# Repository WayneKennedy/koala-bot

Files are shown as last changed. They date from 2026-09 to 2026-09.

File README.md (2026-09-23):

# koala-bot 🐨🤖

An open-source, 3D-printable family of small companion robots — nature-inspired,
affordable, and fully documented (build video + full BOM + software).

**Status:** pre-alpha — *design phase*. Mechanics, electronics, and software are
still converging; nothing is built yet. This repo currently holds the **design
record**. See [`docs/roadmap.md`](docs/roadmap.md) for direction and
[`docs/open-questions.md`](docs/open-questions.md) for what's undecided.

## What it is

**Build order (DEC-62):** first train quadruped walking with four TPU feet.
[Footed rear shanks](docs/design/walking/README.md) interchange at the existing
knees with the wheeled shanks; wheels remain the V1 end goal.

The first family member, **Koala (V1)**, is a **self-balancing, wheel-footed
companion** roughly the size and shape of a koala, printable in **PETG on a
200×200 mm bed**. It sits between *locomotion showpiece* and *desk companion*:
- rolls and balances on two wheel-feet (rear legs, wheels at the ankles);
- crouches and stands on articulating knees, leans into turns via 2-DOF hips;
- gestures with 3-DOF dual-purpose front limbs (arms *and* forelegs);
- looks at you with a 3-RPS parallel neck (yaw delegated to the mobile base).

Locomotion is ground-based; a **climbing sibling** is a planned later family
member. Full intent, morphology, and principles: [`docs/concept.md`](docs/concept.md).

## Repo map

| Path | Contents |
|---|---|
| [`docs/`](docs/) | The design record — concept, architecture, decisions, roadmap, BOM, sourcing (**start here**) |
| [`hardware/`](hardware/) | CAD / printable parts (parametric code-CAD — draft v0 lower body) |
| `firmware/` | Real-time MCU code — balance loop, servo bus (planned) |
| `software/` | Pi / ROS2 high-level brain + tooling (planned) |
| [`LICENSING.md`](LICENSING.md) | Tri-licence (hardware / software / docs) |

## Docs are written AI-first

Most docs assume an **AI assistant is the primary reader** — dense, factual,
cross-referenced, greppable — and every artefact meets the **4Cs**
(Correct · Complete · Coherent · Concise). See [`AGENTS.md`](AGENTS.md).

## License

Tri-licensed — `CERN-OHL-S-2.0` (hardware) · `MIT` (software) · `CC-BY-SA-4.0`
(docs). See [`LICENSING.md`](LICENSING.md). Full licence texts are in `LICENSES/`.

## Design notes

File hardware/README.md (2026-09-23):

# hardware/

Parametric build123d CAD, CERN-OHL-S-2.0. Current 2026-09-19 CAD implements
recessed **roll → pitch → elbow** front limbs and **pitch → roll → knee** rear
limbs, with rear ankle drives and replaceable TPU front pads. Design, assembly,
dimensions and remaining acceptance gates:
[cad-integrated-design.md](../docs/cad-integrated-design.md).

**2026-09-21:** the first build uses four TPU feet (DEC-62). `foot_shank` v1
replaces each complete wheeled rear shank at the existing knee; the same
`front_contact_pad` v1 fits all four feet. The default viewer configuration is
`walking`; `quadruped` and `upright` retain the wheeled geometry.
[Print files, assembly and evidence](../docs/design/walking/README.md).

## Current CAD

The torso now wraps the front A volume, with a **10 mm socket-lip recess**,
removable front-access shoulder cassettes and a cap at body Z183.5; the
hip-to-shoulder axis separation remains **150 mm**. The front carrier, upper arm
and forearm apply the rear redesign's broad print planes, open forks and
accessible supports. Front B/C shafts are parallel. The main assembly carries
DEC-61's **45° rear pitch socket mount**, with rear driver corridors through the
actual torso. [Front revision and evidence](../docs/design/front-redesign/README.md).

`params.py` supplies body/interface dimensions. `servo_iface.py` implements the
measured four-ear SO-101 saddle and horn references. `parts/links.py` carries the
rear links/carriers; `parts/front.py` implements the front chain,
`parts/shoulder_mount.py` its independent cassettes, and `parts/pelvis.py` the
unchanged proven root socket. `parts/torso.py` and `parts/e_tray.py` complete the
chassis. `parts/neck_space.py` reserves small STS3032M neck-servo space and a
cartridge interface; it does not build an accepted 3-RPS mechanism or neck print.
`body_plan.py` and `assembly.py` share the declared pose geometry; front and rear
use different serial joint transforms.

Source paths above are relative to `src/koala_hardware/`. All commands below
run from `hardware/`:

```sh
uv run python -m koala_hardware.export
uv run python -m koala_hardware.assembly
uv run python -m koala_hardware.audit
uv run python -m koala_hardware.audit --fallback --nominal-only
uv run python -m unittest discover -s tests
uv run python -m koala_hardware.body_plan --output ../docs/design --cad
uv run python -m koala_hardware.viewer --build
uv run python -m koala_hardware.mjcf          # MuJoCo model -> sim/koala_walking.xml + meshes/ (--crude: capsule visuals); docs/architecture.md
```

Exports: `build/stl/`, `build/step/`, `build/renders/`, `build/manifest.txt`.
`sim/` holds the generated MuJoCo model: one visual STL per rigid body in `sim/meshes/` (2.7 MB,
committed; regenerate after any CAD change), explicit per-body inertia from the BREP, and the
assumptions in the XML header. `mjcf_check.py` loads it from any venv that has MuJoCo (not a
dependency here) and reports masses, CoM against the feet, a 3 s stand and a render.
Full assemblies are `build/step/koala-walking.step`, `koala-quadruped.step` and `koala-upright.step`.
Every handed print has explicit left/right files. Removed part outputs are
pruned. The exporter regenerates the printed and fastening blocks in
[the BOM](../docs/bom.md); never hand-edit them. Slice results count only when
their SHA-256 matches the current STL.

Every structural print must be one valid solid, export a watertight positive-volume
STL and fit the 200 mm bed in its
stated orientation. Local supports/brims are explicit under DEC-39; flagged
surface areas remain visible in the manifest/BOM and need layer inspection.
They are not a reason to reintroduce unnecessary structural seams.

`audit.py` checks the measured interface, selected screw/tool paths, motor
insertion, real frame contacts and sampled full assemblies including nominal
fastener heads. `--fallback` uses the conservative stepped case instead of the optional
local STEP. Reports are `build/audit.json` and `build/audit-fallback.json`.
Samples are not continuous motion, loaded operating limits or physical fit.
Head placement and mounting are undecided; the placeholder is omitted from
structural CAD/viewer. Neck, complete battery/electronics packaging and
harness/guards remain open. `leg_sizing.py` retains the explicitly historical
DEC-32 analytical study; it does not size the current robot.

## Viewer and independent images

**DEC-46/48:** sliders use pose-dependent mechanical-clearance ranges for the
printed parts and nominal hardware. The static build warms geometry/engine-hashed
caches using Node.js. A browser worker recomputes bounds after each change.
The search uses 0.25° samples and a 2° reserve before the first obstruction;
these are not calibrated servo or loaded operating limits. Ground contact and
complete harnesses are outside the search. Current main-viewer browser and
solid-CAD endpoint checks are in the
[front revision evidence](../docs/design/front-redesign/README.md#digital-evidence-and-limits).
The earlier `docs/design/manufacturing/travel-endpoints.json` predates the
current links; each report validates only its recorded revision.

Build the separate rear-leg review with `uv run python -m koala_hardware.rear_leg_review`
(add `--thigh-options` for the 2026-09-19 thigh print-form comparison, left leg
option 1, right leg option 2: [record](../docs/design/rear-leg/thigh-options/README.md);
`--thigh-flat` for the owner's chosen one-piece tapered thigh on both legs:
[record](../docs/design/rear-leg/thigh-flat/README.md));
the existing server then exposes it at
[rear-leg/](https://blake.tail13a0c0.ts.net:8443/rear-leg/).

[Blake viewer](https://blake.tail13a0c0.ts.net:8443/) is the canonical instance
(DEC-35), served by [systemd/koala-viewer.service](systemd/koala-viewer.service).
It serves a static build. After source changes, run `viewer --build` on blake
and reload; a service restart also rebuilds. The body selector switches between
walking, wheeled quadruped and wheeled upright snapshots. Sliders apply joint adjustments, **not a
validated rise trajectory or safe operating limits**.

For a local viewer:

```sh
uv run python -m koala_hardware.viewer --serve --no-open --port 8020
```

For browser/CAD parity, with Playwright Chromium installed or
`PLAYWRIGHT_CHROMIUM` set:

```sh
uv run --with playwright python tests/viewer_smoke.py
```

Independent PNG/SVG drawings and structural views are in
[docs/design/](../docs/design/README.md), including copies on blake for iPad
Files. Refresh the kinematic PNGs with:

```sh
uv run --with playwright python -m koala_hardware.body_plan --output ../docs/design --cad --png
```

The Parts tab shows per-part `printable` tags, materials, print orientations and assembly notes;
it is not a packed print plate. Bought references are not printable parts.

## Physical acceptance

The maintainer confirms ST3215 fit in SO-101 parts in PLA+/PETG (DEC-33).
There is no repeat-gauge/caliper prerequisite. The two `coupon_socket_*`
designs remain available to investigate a specific new fit issue. Check the
current assembly's insertion/removal, M2/M3 engagement, centre-head/boss
clearance, Back washers, axial preload and real connector access. Log results
by exact print version in [the test log](../docs/test-log.md).

Root socket v1 is physically proven with its recorded ear-hole support caveat;
hip carrier v1 has plate 2 slices but no recorded physical result. Continue with version-specific fitting,
one rear leg, the pair, front limbs and documented load/creep/transition checks.
Actual masses, CoM and power budgets remain open. No digital check closes these gates.

`slice_remote.py` must not run on the printer host while printing is active.
Local slicing does not submit or start a print. Generic motor/hole/insert
coupons remain available; record results, including no change, in the test log
and store calibrated constants in `params.py`.

## Local manufacturing slices

`uv run python -m koala_hardware.manufacturing_slices` uses local PrusaSlicer,
reads the shared printer profile from the sibling 3d-printing checkout and adds
`print/manufacturing-*.ini` project settings (support from the bed only, never off the part:
the house rule, learned on plate 1; `-tree.ini` for organic support, one part per job). It records exact STL hashes and
layer-path images in `docs/design/manufacturing/`. It never submits a print.
Changed torso v5, shoulder mount v1, front carrier v3, upper arm/forearm v2 and
thigh v3 remain `unknown`; local toolpaths alone do not establish physical
printability. Root socket v1 is `proven` with its documented caveat; unchanged
parts retain their recorded tags. See [the part review](../docs/part-design-review.md).
TPU settings are provisional until matched to the actual spool.

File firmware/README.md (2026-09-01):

# firmware/

Real-time MCU code (planned - Phase 1). The "spinal cord".

- Runs the **balance loop** (IMU -> PID -> wheels, ~200-1000 Hz, deterministic), the
  servo-bus driver, encoders, safety.
- **micro-ROS** node exposing the topic contract (see [`../docs/architecture.md`](../docs/architecture.md)).
- MCU: Teensy 4.0 (DEC-18). Licence: `MIT`.

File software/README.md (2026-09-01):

# software/

Pi 5 / ROS2 high-level brain + tooling (planned - Phase 1). The "cerebrum".

- Perception (camera-eyes), behaviour/mission, LLM personality, networking.
- Sends setpoints to the MCU, reads telemetry - never runs the balance loop.
- Licence: `MIT`.

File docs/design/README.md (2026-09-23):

# Engineering drawings and CAD

**2026-09-21 addition:** [walking first build](walking/README.md), with four
identical TPU feet and interchangeable `foot_shank` v1 rear links. The main
viewer opens in this configuration; the wheeled snapshots remain selectable.

**Current 2026-09-19 revision:** [recessed roll-first front limbs](front-redesign/README.md),
[small-servo neck provision](neck-provision.md),
[design and assembly](../cad-integrated-design.md), and
[part-by-part printability](../part-design-review.md). The torso wraps the front
A modules while retaining 150 mm hip-to-shoulder spacing. New front parts and
changed torso/thigh remain unprinted; older slices validate only matching hashes.

The [rear-leg record](rear-leg/README.md) documents DEC-57/58's origins and later
print-form studies. DEC-61's inclined rear mount is now implemented in the main
assembly. Current thigh v3 corrects rounding; shank v2 is unchanged. Earlier
[carrier-orientation alternatives](carrier-orientation/README.md) and
[front-carrier flat-back study](front-carrier/README.md) are historical, not
competing current mounts.

[SO-101 source templates and interface comparison](so101/README.md) retain the
measured construction reference. [Manufacturing records](manufacturing/README.md)
distinguish local slices from physical proof; root socket v1 is proven with its
recorded ear-hole caveat.

**Historical knee packaging study, deferred by DEC-43:**
[PNG](knee-packaging.png) · [SVG](knee-packaging.svg) ·
[Results](knee-packaging.json) · [Interpretation](../knee-drive-packaging.md).
This records the rejected knee-wheel detour and is not the current structure.

These PNGs open directly in the iPad Files app. Copies are kept in this same
repo path on blake.

| View | Quadruped | Upright |
|---|---|---|
| Dimensioned body master | [PNG](body-quadruped.png) | [PNG](body-upright.png) |
| Scalable body master | [SVG](body-quadruped.svg) | [SVG](body-upright.svg) |
| Actual structural CAD, side | [PNG](cad-quadruped-side.png) | [PNG](cad-upright-side.png) |
| Actual structural CAD, perspective | [PNG](cad-quadruped.png) | [PNG](cad-upright.png) |
| Kinematic STEP reference | [STEP](body-quadruped.step) | [STEP](body-upright.step) |

The master drawings and detailed CAD share their joint centres: 70 mm upper
arms, 75 mm forearms plus 25 mm hand extensions to Ø32 mm ball centres,
85/90 mm rear links, 150 mm torso, 450 mm upright height and 220 mm rear track.
Unrolled front ball centres are now 190.23 mm apart and 260 mm ahead of the
rear wheels in supported stance. Only the rear Ø80 wheels are driven. Front
shoulders are roll → pitch; rear hips remain pitch → roll. The body-master head outline is a sizing allocation only; it is omitted from
the structural CAD and viewer because position and mounting are undecided.

[Joint coordinates](body-plan.json) · [Design and assembly](../cad-integrated-design.md) ·
[Digital validation](cad-validation.json) · [Body-layout rationale](../body-layout.md).

## Individual structural prints

Exporter PNGs show the print orientation; files ending `-views.png` show native
CAD coordinates for shape review. Current [layer plots](front-redesign/README.md#local-slicing-and-support-review)
show the chosen bed faces. Left/right STL and STEP files are generated separately.

| Print | Image |
|---|---|
| Proven root socket v1 (four physical prints) | [PNG](parts/root_socket_right.png) |
| Recessed shoulder cassette v1 | [Four views](parts/shoulder_mount-views.png) |
| Roll-first shoulder carrier v3 | [Four views](parts/shoulder_carrier-views.png) |
| Rear hip carrier v1 | [PNG](parts/hip_carrier_right.png) |
| Drive/idler socket slots | [PNG](so101/socket-slot-comparison.png) |
| Corrected thigh v3, 85 mm | [Four views](parts/thigh-views.png) |
| Upper arm v2, 70 mm | [Four views](parts/upper_arm-views.png) |
| Shank v2, 90 mm | [PNG](parts/shank_right.png) |
| Footed rear shank v1, 90 mm | [Four views](parts/foot_shank-views.png) |
| Forearm v2 and keyed hand end | [Four views](parts/forearm-views.png) |
| Replaceable Ø32 TPU contact | [PNG](parts/front_contact_pad.png) |
| Extended torso v5 | [Four views](parts/torso_frame-views.png) |
| Electronics tray | [PNG](parts/e_tray.png) |
| Two-print acceptance rig | [Saddle](parts/coupon_socket_saddle.png) · [Fork](parts/coupon_socket_fork.png) |

Full structural STEP assemblies are generated in
`hardware/build/step/koala-walking.step`, `koala-quadruped.step` and `koala-upright.step`; the current
part STL/STEP sets are in `hardware/build/stl/` and `hardware/build/step/`.
These build outputs also exist on blake. Original upstream reference STEPs
remain unchanged in `hardware/vendor/`; they are not koala prints.

## Regenerate

From `hardware/`:

```sh
uv run python -m koala_hardware.export
uv run python -m koala_hardware.manufacturing_slices
uv run python -m koala_hardware.assembly
uv run python -m koala_hardware.audit
uv run python -m koala_hardware.audit --fallback --nominal-only
uv run --with playwright python -m koala_hardware.body_plan --output ../docs/design --cad --png
uv run python -m koala_hardware.viewer --build
```

PNG rendering requires Playwright Chromium, or `PLAYWRIGHT_CHROMIUM` set to an
installed binary. CAD scene PNGs come from the browser regression captures;
individual print PNGs come from the exporter. No image is evidence of slicing,
physical fit, continuous collision clearance, strength or a validated rise.

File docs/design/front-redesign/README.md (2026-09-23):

# Recessed roll-first front limbs — 2026-09-19

**Unprinted revision, not a banked decision.** The owner requested the four CAD
review findings be fixed, then the rear redesign's printability lessons applied
to roll-first front limbs, with the torso extended around recessed A servos and
provision for the three small neck servos. This record describes the resulting
prototype. [Current chassis and assembly](../../cad-integrated-design.md) ·
[Printability by version](../../part-design-review.md).

## Geometry and visual review

| Item | Result | Review image |
|---|---|---|
| Torso v5 | 150 mm hip-to-shoulder spacing retained; cap at body Z183.5; ±47 mm sides, shallow forward chest step, rear screw-driver corridors | [Four views](../parts/torso_frame-views.png) |
| Shoulder mount v1 | Separate left/right cassettes support unchanged proven root sockets; socket lips at ±37 mm give 10 mm recess; four front-access M3×20 per side | [Four views](../parts/shoulder_mount-views.png) |
| Shoulder carrier v3 | Longitudinal A roll, B pitch 40 mm outboard; broad common block/socket bed plane and open driver tunnels | [Four views](../parts/shoulder_carrier-views.png) |
| Upper arm v2 | 70 mm centres, parallel B/C shafts, thickened cup wall sharing the outer fork's print plane | [Four views](../parts/upper_arm-views.png) |
| Forearm v2 | 100 mm elbow-to-pad centre, longer open elbow fork, flat tapered shaft, unchanged keyed TPU pad | [Four views](../parts/forearm-views.png) |
| Thigh v3 correction | Earlier successful fillets now survive later split-group rounding operations; joint datums unchanged | [Four views](../parts/thigh-views.png) |

**Does the design look stupid?** Individual review: **no**. The torso/cassettes
form a compact cage with broad rails, a shallow chest step and inward socket
flanges, without outriggers or disconnected features. The front carrier and
links have continuous printable forms rather than thin unsupported decorative
features. They are acceptable structural prototypes, not an accepted finished
shell. V5's inward dorsal taper was also inspected in multiple views: it
narrows the upper back without adding a backpack or increasing the 94 mm front
width / 82 mm depth envelope. The
[assembled body views](body-views.png) were also reviewed: depth stays compact,
the front shoulder span approaches the rear wheel span, and the different
front/rear limb forms look deliberate. The head remains a sizing allocation,
so this is not approval of a finished koala shell or loaded gestures.

The recess is measured from the torso side envelope to the **socket lip**;
A's output region, horns and moving carrier project outside it. A centres are
110.23 mm apart, pitch centres 190.23 mm apart. Rear pitch centres remain
52.5 mm apart and rear wheel track remains 220 mm. Left/right symmetry is
retained; front and rear use different serial joint orders by design.

The first extended torso (v4) cleared the nominal pose but its dorsal rails
clipped the front carrier at **+1° roll**. V5 tapers those rails from Y±43 to
Y±29 over body Z106…122; the outer width, depth and socket-lip recess stay
unchanged. The cartridge hole pattern shifts +10 mm in X to clear the upper
rails. This is a correction found by moving-package checks, not evidence that
a nominal screenshot alone established travel.

The B35 shoulder-carrier v2 trial also exposed a limitation beyond nominal
checks: the full upper-arm/A-case sweep stopped at about **+6° roll**. Final
carrier v3 puts B **40 mm** outboard. At the examined ±28/29/30° roll samples
in both saved poses, B39 left 0.765 mm upper-fork / 1.065 mm horn-head clearance
to the conservative A case; B40 increases those sampled minima to
**1.765 / 2.065 mm**. Upper arm/forearm v2 and torso v5 stay unchanged.
The larger margin is a geometric allocation, not a proven loaded range.

The [neck provision](../neck-provision.md) reserves small STS3032M space and
four generic cartridge mounts, including fixed-lead routing allowance. These
reference boxes neither establish the bought variant's fit nor solve 3-RPS
linkage geometry. No new neck print is claimed.

## Printability and service

New shoulder mount v1, torso v5, front carrier v3, upper arm/forearm v2 and thigh
v3 remain **`unknown`** despite local slicing; physical support removal, fit and
strength are unverified. Root socket v1 remains **`proven`** with its ear-hole
support caveat. Unchanged shank v2 and hip carrier v1 retain `assumed`.

The carrier prints on its common block/cup floor, the upper arm on its shared
drive-side fork/cup plane, and the forearm on its broad −Y face. Open forks
make supports accessible. Seven short/narrow upper-arm junction edges reject
R2 and remain sharp; the builder warns explicitly instead of silently undoing
rounding. The accepted ear seats, horn webs and driver approaches remain.

Recessing A would obstruct installed inboard root screws. **Load the four frame
nuts into the bare cassette first:** a fitted root blocks the two inner nuts'
straight insertion paths. Then bolt the root to the cassette on the bench and
attach the complete cassette to the ventral frame with four front-access screws.
For root service, remove those frame screws and slide the cassette **laterally
outward**, keeping the opposite A module installed. The seam has a service purpose; links remain single prints.
This 2026-09-19 wheeled revision uses 26 physical prints from 18 designs /
26 handed exports, including six coupon designs. The later
[walking addition](../walking/README.md) adds an interchangeable rear-shank
design and two extra TPU pads for that configuration.

## Local slicing and support review

[Machine-readable slice records](slices.json) identify each STL/G-code version
and hash, plus the base profile and override hashes. PrusaSlicer **2.7.2** came
from the Ubuntu noble package, extracted locally with dependencies; no host
installation or printer connection was used. Review settings were **0.2 mm
layers, four walls, 30% gyroid, 4 mm brim and organic supports from the bed only**.

| Current part | Selected deposited-layer views |
|---|---|
| Forearm v2 | [Left](forearm_left-layers.png) · [Right](forearm_right-layers.png) |
| Shoulder carrier v3 | [Left](shoulder_carrier_left-layers.png) · [Right](shoulder_carrier_right-layers.png) |
| Shoulder mount v1 | [Left](shoulder_mount_left-layers.png) · [Right](shoulder_mount_right-layers.png) |
| Upper arm v2 | [Left](upper_arm_left-layers.png) · [Right](upper_arm_right-layers.png) |
| Thigh v3 | [Left](thigh_left-layers.png) · [Right](thigh_right-layers.png) |
| Torso v5 | [Layer views](torso_frame-layers.png) |

The selected layer plots show broad bases and support trees outside the solids
or in open forks/cups, without an enclosed support cage in the inspected layers.
The torso v5 plot shows branches through its open cage to the opposing rails
and cap. **All 11 final review slices match the current STL versions/hashes**,
including carrier v3 and torso v5, with **zero recorded slicer diagnostics**.
The final carrier layers and B40 body views have been inspected. Selected
layers do not establish every layer start or physical support removal;
surface quality, fit and strength remain unverified and changed parts stay
`unknown`. Tiny forearm STL coordinate roundoff was corrected by persisting the
same default vertex merge already used in mesh validation; BREP geometry and
merge tolerance did not change. [Digital correction](../../test-log.md#2026-09-19--forearm-v2-stl-roundoff-persistence-corrected-digital-only).

Shank v2 is outside this 11-slice batch. [OQ-22](../../open-questions.md)
records earlier organic slices with STL hash prefixes 335d9f74 (left) and
ae2ac311 (right), matching the current exports; those G-code files and layers
were not re-reviewed here. Older manufacturing-report shank slices predate v2.

To reproduce one organic review slice, run from `hardware/` with an
organic-capable PrusaSlicer and the sibling `3d-printing` checkout:

```sh
mkdir -p build/manufacturing
prusa-slicer \
  --load ../../3d-printing/reference/ender5s1_petg_koala.ini \
  --load print/manufacturing-petg-tree.ini \
  --export-gcode \
  --output build/manufacturing/upper_arm_right-v2-tree.gcode \
  build/stl/upper_arm_right.stl
```

Substitute the current exported part name and version for other parts, slicing
one at a time. Match the recorded slicer/profile hashes when comparing this
review's toolpaths. The command writes a local file; it does not submit a print.

## Digital evidence and limits

The [consolidated validation record](../cad-validation.json) links the final
versions, exports, slices and main/rear checks.

The [complete driven-package report](driven-package-clearance.json) is the
primary shoulder roll check: **outward-positive commanded roll −30…30° at 2°
intervals**, in both saved pitch/elbow configurations. It checks the entire
right moving front chain and hardware against its fixed A imported/caliper
cases, socket module, cassette and fixings: **31 samples / 2,604 pairs per
pose, zero overlap**. It covers the upper-arm/A-case interaction missed by the
earlier carrier-only trial.

The [installed-front report](installed-front-clearance.json) also moves **both
front limbs** at roll −30/−25/0/+25/+30°, with the rear limbs nominal, in both
saved poses and with both imported/caliper cases. All pairs involving the
moving fronts participate against the torso, catalogue neck envelopes, fixed
roots, opposite front limb and stationary rear hardware, except the intended
owning-socket contact regions: **20 configurations / 1,236 candidate solid
pairs, zero hits**. These two reports identify their geometry-source hashes.

Additional evidence has narrower scope:

| Check | Scope and result |
|---|---|
| [Adjacent joints](local-clearance.json) | 1° samples with both case models: native carrier-only roll −30…60°, pitch ±90°, elbow 0…120°; 2,296 pairs, zero overlap. The native roll axis/range is not the whole-limb commanded range above. |
| [B-offset study](roll-offset-study.json) | Documents the B35 obstruction and B40 choice; sampled conservative A-case margins at ±28/29/30° are 1.765 mm for the upper fork and 2.065 mm for horn heads. |
| [Dorsal-rail sweep](shoulder-rail-sweep.json) | Final B40/carrier v3 and torso v5: 12 moving front-chain solids against conservative unfilleted rail/transition envelopes over ±30° roll at 2° in both saved poses, zero overlap. |
| [Complete assembly audit](assembly-audit.json) | 62 samples around both saved poses pass; each nominal pose checks 180 pairs. Also checks the 19-angle interface rig, insertion, frame contact and driver paths. |
| [Fallback audit](assembly-audit-fallback.json) | Both nominal poses pass with conservative parametric servo cases; 180 pairs each. |
| Neck and service access | Reserved neck volumes/four cartridge driver paths clear; three service regressions protect cassette nut loading/seating and lateral removal. |
| Python regression suite | **65 tests pass**, including version guarding, front print/kinematic checks and STL closure after merging only identical coordinates. |
| Exports and slicing | **26 handed part exports, two assembly STEP exports, 11 current review slices** pass; generated BOM updated. |
| [Main browser verification](browser-verification.json) | Both poses, all three sliders, mirrored CAD/browser motion, backdrop alignment, part metadata and reset pass; four current captures inspected. |
| [Main viewer endpoints](viewer-endpoints.json) | All 12 initial grouped-slider endpoints checked against the complete assembly with both case models: 24 configurations / 1,452 candidate solid pairs, zero hits. |
| [Rear production review](../rear-leg/README.md) | Refreshed current parts, sections and views; both browser poses/seven checks and all 12 initial bounds plus four combined solid-CAD configurations pass. Front/neck geometry is omitted from this separate review. |

The main viewer rolls all four limbs together. Its initial common roll range
is **−5.5…29.25°** in quadruped and **−5…29.25°** upright, including the 2°
search reserve. Rear motor proximity sets the inward bound; the front socket/
carrier sets the outward bound. The front-only ±30° checks above leave the
rear joints nominal and therefore do not establish that grouped range.

The solid intersection threshold is **0.01 mm³**. These are finite samples,
with stated pose/obstacle coverage, not continuous swept volumes, calibrated
servo limits or loaded motion. Ground interaction, full cables, guards and
as-built tolerances are not established. The earlier four findings and their
corrections are recorded in the [test log](../../test-log.md#2026-09-19--four-cad-review-defects-corrected-digital-only).

The **main browser smoke and solid-CAD endpoint checks pass**; its four current
pose/view captures have been inspected. A [metadata-only refresh](viewer-metadata-refresh.json)
updates prior hip/shank slice notes and verifies every non-note scene field is
unchanged. The rear review also passes its browser and endpoint checks. Of its
16 broader exploratory rear-assembly samples, 15 clear; quadruped pitch −45°
intersects torso/thigh outside the current −28.25° viewer bound. That sample is
not accepted travel. Earlier manufacturing reports and
thigh v2 slices do not validate these revised parts. No physical print,
fitting, support removal, load/creep or loaded transition is asserted by this record.

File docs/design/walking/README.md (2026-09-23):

# Walking first build — interchangeable rear shanks

**2026-09-21, DEC-62.** `foot_shank` v1 replaces each complete wheeled `shank`
at the existing knee. It has no motor mount or drive hardware and uses the
**unchanged `front_contact_pad` v1**: four identical Ø32 TPU feet on the first
robot. Wheeled shank v2 remains the V1 end goal.

[Four-view shape review](../parts/foot_shank-views.png) ·
[Assembly](assembly.png) · [Side](assembly-side.png) ·
[Walking schematic](../body-walking.png) · [SVG](../body-walking.svg) ·
[Main viewer](https://blake.tail13a0c0.ts.net:8443/) (opens in “Walking · four TPU feet”).

## Parts and exchange

| Print | Qty for walking | Files |
|---|---:|---|
| `foot_shank_left` v1, PETG | 1 | [STL](../../../hardware/build/stl/foot_shank_left.stl) · [STEP](foot_shank_left-v1.step) |
| `foot_shank_right` v1, PETG | 1 | [STL](../../../hardware/build/stl/foot_shank_right.stl) · [STEP](foot_shank_right-v1.step) |
| `front_contact_pad` v1, TPU | 4 total | [STL](../../../hardware/build/stl/front_contact_pad.stl) |

STLs are generated local build outputs; run the exporter after cloning.
The full structural assembly is
[`koala-walking.step`](../../../hardware/build/step/koala-walking.step).
The generated [BOM](../../bom.md) counts **28 physical prints walking** and
**26 wheeled**, excluding coupons and unfitted alternatives from each total.

Each rear foot is 90 mm from knee axis to ball centre; front reach stays
100 mm. Native X is the knee shaft, +Z points toward the pad. The rear knee's
36.4 mm horn span, square holes, head recesses and driver paths are retained.
No new ankle joint or structural seam is introduced. The front v2 geometry
and all existing part versions are unchanged; the ledger adds `foot_shank` v1.

Insert the captive M3 nut from the shank's side before fitting the keyed pad.
Use the same recessed M3×20 screw and plain washer as the front foot. Mount
the fork on the knee's drive/idler horns using the existing eight square
screws, drive-centre retention and four idler washers. For conversion,
support the robot, isolate power and exchange the whole handed lower links
at those horn interfaces; the knee servos stay in the thighs. Fit the
retained motor/hub/wheel packages to wheeled shank v2 and use the matching
kinematics, calibration and mass model.

## Stance and clearance scope

The walking CAD reference retains the supported torso and front limb pose.
Rear contact X remains −55 mm; pad centres are Z16 instead of the wheel
axles' Z40. Rear knees are re-solved for the retained 85/90 mm links. All four
TPU surfaces touch Z0. Neutral rear foot spacing is **132.6 mm**; front foot
spacing is 190.23 mm. **220 mm is the wheeled track**, not walking-foot spacing.
The `walking` reference is a standing configuration, not a trained gait.

- Four-view shape gate passed before export: short front-style taper, open
  fork and broad flat print face; no leftover motor bracket.
- Both handed exports are connected, valid solids with closed positive-volume
  meshes; each fits within **49.0 × 103.4 × 20.8 mm** in its print orientation.
- Regression checks cover common horn interfaces/driver paths, identical
  keyed terminal geometry, nut access, pad/head clearance and per-build BOM
  counts. The full Python suite passed 71 tests; the JavaScript transform
  regression also passed.
- The complete shank **and pad** clear the adjacent thigh and knee case at
  **0–120° bend in 10° increments**, with imported and conservative cases.
  This local check is separate from whole-robot slider travel.
- [Assembly samples](assembly-samples.json): 27 shared-control combinations
  at −5/0/+5° roll/pitch/bend plus four opposed-left pitch/bend samples pass.
  [Nominal audit](assembly-audit.json) and
  [conservative-case audit](assembly-audit-fallback.json) include all three
  configurations and the existing mounting/access checks.
- [Viewer endpoints](viewer-endpoints.json): all six initial walking slider
  endpoints pass independent solid-CAD checks with both case models. Browser
  checks cover walking and both retained wheeled poses, left/right motion,
  pad/shank tags, backdrop alignment and resetting the controls.
  [Validation record](validation.json) lists the commands and results;
  [source/export manifest](manifest.json) records the reviewed version and hashes.

These are discrete, nominal CAD checks. They do not prove continuous travel,
floor clearance during slider motion, cable routing, loaded gait, strength or
safe servo limits. Ground reactions, training setup and physical foot/load
acceptance remain OQ-16/17/19.

## Print approach and local slices

`foot_shank` v1 is **unknown / unprinted**. Print with its broad native −Y face
on the bed. The existing fork bores/head reliefs and nut-slot roof need
accessible local supports. The new rear part inherits the front construction,
not physical proof of fit or strength.

[Slice records and hashes](slices.json) ·
[Left layers](foot_shank_left-layers.png) ·
[Right layers](foot_shank_right-layers.png).

Both handed v1 exports were sliced with the recorded shared PETG profile and
Koala's `manufacturing-petg-tree.ini`: organic support from the bed only,
0.2 mm layers, four perimeters, 30% infill, 4 mm brim. Each has 104 layers,
zero reported slicer diagnostics and approximately **3 hours / 30 g PETG**.
Selected layers show a continuous shaft/taper and open support access at the
fork and key; they do not prove every layer start or physical removal.
The unchanged TPU pad retains its existing slice record; material grade,
retention, traction and wear remain unverified. Nothing was printed.

From `hardware/`, regenerate CAD and checks:

```sh
uv run python -m koala_hardware.render_views foot_shank
uv run python -m koala_hardware.export
uv run python -m koala_hardware.assembly
uv run python -m koala_hardware.audit --nominal-only
uv run python -m koala_hardware.audit --fallback --nominal-only
uv run python -m unittest discover -s tests
uv run python -m koala_hardware.body_plan --output ../docs/design --cad --png
uv run python -m koala_hardware.viewer --build
```

For either exported shank, the local slice command is:

```sh
prusa-slicer --load ../../3d-printing/reference/ender5s1_petg_koala.ini \
  --load print/manufacturing-petg-tree.ini --threads 2 --export-gcode \
  --output build/manufacturing/foot_shank_right-v1-tree.gcode \
  build/stl/foot_shank_right.stl
```

Use `left` for the other hand. The recorded run used the temporary extracted
PrusaSlicer executable named in `slices.json`; no host installation or printer
connection was required.

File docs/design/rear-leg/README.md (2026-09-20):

# Production rear-leg review — 2026-09-19

This review shows **thigh v3, shank v2 and the complete torso frame v5** with
DEC-61's 45° rear pitch sockets and the retained hip carriers. It uses the same
production geometry as the main assembly. Front limbs and shoulder cassettes,
neck envelopes, electronics, cables and guards are omitted from this rear-only
viewer.

[Live review over Tailscale](https://blake.tail13a0c0.ts.net:8443/rear-leg/) ·
[Quadruped view](rear-leg-quadruped.png) · [Upright view](rear-leg-upright.png) ·
[30° outward roll](rear-leg-roll-30.png) · [Thigh v3](rear-leg-thigh-v3.png) ·
[Structural sections](sections.png).

## Geometry and manufacture

The **85 mm thigh**, **90 mm shank**, **220 mm neutral rear track** and both
bought ankle drives are retained.

- **Thigh v3 — `unknown` printable:** the stepped yoke, R6.3 fork roots and
  knee case clocked 90° about its unchanged shaft remain. The idler-side cheek
  reaches the cup-floor plane through one flat taper. R2 outer rounding and
  R1.5 cup rounding now accumulate correctly: later successful fillet groups
  no longer restore earlier sharp edges. Horn seats and driver paths remain
  intact. Print on the cup-floor plane with accessible tree support beneath
  the drive-side cheek and pads. Current left/right slices have zero diagnostics;
  inspected layers retain access for support removal. Physical removal and
  loaded testing are still required.
- **Shank v2 — `assumed` printable:** the extended open knee fork, R6.3 fork
  roots and R5 motor-support roots remain. Its motor-mount outer face and
  drive-fork outer face share one print plane. Fit the motor axially from
  inboard and install all six face screws before the hub and wheel. Support
  beneath the idler fork and motor-bore roof remains to be reviewed physically.

Both revisions are **unprinted**. Thigh v3 has hash-matched
[slice records](../front-redesign/slices.json) and inspected
[left](../front-redesign/thigh_left-layers.png) /
[right](../front-redesign/thigh_right-layers.png) layers. Shank v2 has
[earlier recorded bed-only organic slices (OQ-22)](../../open-questions.md)
matching the current STL hash prefixes; check its unsupported motor-bore roof
for sag when printed.
The separately recorded
[root socket v1 print](../../test-log.md) does not establish their fit or strength.
[Current exported STL hashes, dimensions and surface metrics](manufacturing.json)
record watertight, positive-volume meshes in their declared print orientations;
these metrics are not a slicing or physical-print result.

[Thigh right STEP](thigh-right.step) · [Thigh left STEP](thigh-left.step) ·
[Shank right STEP](shank-right.step) · [Shank left STEP](shank-left.step).
These part exports are already on the bed.
[Quadruped assembly STEP](rear-leg-quadruped.step) and
[upright assembly STEP](rear-leg-upright.step) contain only project geometry.
The viewer distributes measured case/horn envelopes; the local vendor servo
STEP is used for independent checks and is not redistributed.

## Clearance evidence

[Solid-CAD checks, part versions and source hashes](clearance.json) record:

- **61 local thigh-roll samples, −30° to +30° at 1°:** thigh against its carrier
  and both imported and conservative measured B case references.
- **121 local knee-flexion samples, 0° to 120° at 1°:** shank against the thigh
  and both C case references.
- Horn bores, head/washer pockets and straight driver approaches; C's ear
  fixings, cable corridor and sampled case-insertion positions; axial motor
  insertion and all six motor-face driver paths.
- Broader rear-assembly samples with both legs, motors, wheels, nominal
  hardware and the actual torso. Each sample records its own collisions;
  local ranges do not establish whole-assembly travel.

Of the sixteen exploratory assembly samples, fifteen clear. Quadruped hip
pitch −45° intersects the torso at both thighs (903.890 mm³ per side); the
viewer limits that direction to **−28.25°**. The colliding exploratory pose is
outside the accepted viewer range.

The [viewer limits](viewer-limits.json) use 0.25° mesh samples with a 2° reserve
before the first obstruction. Hidden parts and the opposite leg remain
obstacles. [Independent endpoint checks](viewer-endpoints.json) check its twelve
initial bounds and four combined configurations against solid CAD with imported
servo cases. [Browser checks](browser.json) cover both cached poses, motion,
current part versions and printability tags.

Any ±180° bound is the search ceiling, not a confirmed physical stop. Ground
contact, omitted front/neck/electronics components, cables, physical indexing,
tolerances and loaded transitions remain outside this review. Use the main
viewer when checking the complete modelled chassis.

## Earlier studies and reproduction

The [orientation study](thigh-orientation-study.png),
[frame-versus-bolted-cheek comparison](thigh-options/README.md) and
[one-piece tapered-thigh study](thigh-flat/README.md) are historical evidence.
Their archived files remain unchanged; the production viewer displays the
current rounded thigh v3. The earlier
[socket-angle comparison](../carrier-orientation/README.md) records the origin
of the accepted 45° mount.

From `hardware/`:

```sh
uv run python -m koala_hardware.export
uv run python -m koala_hardware.rear_leg_review
```

The review command refreshes `hardware/build/viewer/rear-leg/`, clearance and
endpoint records, project STEP exports, native sections and metrics for the
preceding main-export STLs. Browser screenshots and `browser.json` are captured
with `uv run --with playwright python tests/rear_viewer_smoke.py` after the viewer
is served. Set `VIEWER_URL` and `PLAYWRIGHT_CHROMIUM` for another server or local
browser executable. Do not use `--thigh-options` or
`--thigh-flat` when refreshing production evidence.

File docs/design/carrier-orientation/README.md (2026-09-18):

# Rear carrier rest orientation — studies, 2026-09-14/15

## Pitch socket on an inclined torso face — selected proposal, DEC-57

The maintainer initially accepted the angled-fork arrangement below, then
reopened the choice to preserve the simpler current carrier. Their proposal
is to put a non-vertical mounting face into the torso and attach the existing
pitch socket to it. On 2026-09-15 they selected the **45° variant as the proposed
A/B arrangement** and advanced to the [rear thigh and shank](../rear-leg/README.md).
The angled-fork candidate is parked.

[Rotate/compare socket tilts](pitch-socket-tilt.html) ·
[45° placement STEP](pitch-socket-45.step) · [Checks](pitch-socket-tilt.json) ·
[CAD/check builder](../../../hardware/src/koala_hardware/pitch_socket_tilt_study.py).
The local server provides the same preview at `/pitch-socket-tilt.html`.

The study keeps the current DEC-56 carrier and DEC-53 root socket unchanged,
including their print orientations. The pitch case/socket rotates about its
existing lateral shaft; the pitch/roll axes, joint centres and saved leg
coordinates do not move. A 5 mm torso-face patch has eight holes matching
the two modules' captive-nut patterns. It represents the eventual torso's
surface, **not another separate print**. The rest of the torso is omitted.

| Socket tilt relative to the current mounting face | Clear forward-pitch sample in quadruped | Later sample that intersects |
|---|---:|---:|
| Current | −6° in the earlier DEC-56 check | −15° |
| 30° away from the forward swing | −36° | −45° |
| 45° away from the forward swing | −51° | Not searched beyond −51° |

The 45° arrangement passes all tested carrier/roll-case checks against the
root module, pitch case and face patch at pitch 0°, −15°, −30°, −36°, −45°,
−51° and +30° in both saved body poses. All four right module frame-driver
approaches clear the module, case, opposite module and local face patch.
The print orientation declared for the current torso puts the proposed
mounting surface **45° to the bed**, consistent with the maintainer's
support-free slope preference. The root socket and carrier need no new
print geometry. The complete torso walls, their filleted transitions,
access through those walls and any bolt-hole roofs remain to be designed.

These are discrete local checks, not full assembly, continuous travel or
walking acceptance. The face patch is not a completed torso or a direct
replacement for its current flange. DEC-57 holds the 45° proposal; the main
assembly retains its previous torso mount. The separate rear-leg viewer uses
the proposed mount and revised downstream parts. Reproduce this earlier study with
`.venv/bin/python -m koala_hardware.pitch_socket_tilt_study` from `hardware/`.

## Angled forks, retained roll socket — clarification and construction

The maintainer clarified the proposal: keep the pitch socket as currently
mounted and attach the carrier with its fork arms down/rearward at 45°.
The connection to the roll socket and its print orientation are the questions
to resolve. The fork direction need not set the roll socket's angle.

[Rotatable candidate](angled-fork.html) · [Fitted view](angled-fork-assembly.png) ·
[Print orientation](angled-fork-print.png) · [Candidate STEP](angled-fork.step) ·
[Checks and hashes](angled-fork.json) ·
[Reproducible CAD/check builder](../../../hardware/src/koala_hardware/carrier_fork_study.py).
The running local viewer also serves the study at `/angled-fork.html`.

This separate candidate turns the forks **57.53° relative to the current
carrier**, putting their arms 45° down/rearward in the saved quadruped pose.
A continuous wedge joins them to B's socket, whose position and orientation
stay unchanged. Both hip axes and the saved leg coordinates are therefore
retained. The earlier warning about tilting the roll shaft applies to rotating
the entire old carrier, not to this new connecting geometry.

The wedge and socket floor share a flat print base. The part is printed on
that base, independently of its installed angle. R6.3 fork-root fillets, an
R5 socket-root fillet and rear gusset, an R1.5 socket-lip fillet and tapered
2 mm edge bevels retain rounded load transitions and complete horn pads.
The four roll ear-driver corridors are preserved through the new gusset.

The candidate is one valid solid with a watertight STL, **60.6 × 77.7 ×
50.5 mm** in its proposed print orientation and **2,774 mm²** of bed contact.
Fork undersides and hole roofs may need accessible supports; the surface
screen flags 561 mm² for inspection. Printable remains **unknown**: no slice,
support-removal trial or physical print has been performed. The full wedge
is deliberately a first construction: **62.3 cm³ versus 36.6 cm³** for the
current carrier, about 70% more solid volume. Strength and final material
distribution remain unresolved.

Forty-four exact intersection checks pass: the pitch horn heads/washers,
roll ear heads and driver/cable corridors, five servo insertion positions,
the existing thigh at both saved rest poses, and the carrier against the
fixed root module and pitch case at quadruped pitch samples −30°, −20°,
−10°, 0°, +10°, +20° and +30°, plus upright zero. The rotated horn-pad region
is unchanged. These are scoped samples, not complete assembly, continuous
travel, walking, wiring or load acceptance. The fork and its bolt pattern
rotate together; physical servo/horn indexing remains OQ-21. The thigh's
existing fixing obstruction remains OQ-22.

To regenerate the CAD and checks, run
`.venv/bin/python -m koala_hardware.carrier_fork_study` from `hardware/`.
It also writes the ignored `angled-fork.stl` in this directory, already
oriented on the bed. The HTML uses the repository's Three.js and measured
parametric servo envelopes; the exact case checks use the locally available
servo reference identified in the check record.

**This candidate is not selected for production.** The normal viewer,
production part builders, saved poses and generated BOM are unchanged by
this construction study.

## Earlier whole-carrier placement study

[Side-view comparison](comparison.png) · [SVG](comparison.svg) ·
[Exact intersection samples and source hashes](study.json).

The proposed horizontal or 45° carrier is studied here by rotating the whole
existing carrier around the hip pitch pivot. The root module stays fixed in
the saved quadruped pose. Angles describe the direction from the pivot towards
the carrier's block/socket bottom, relative to the ground. The current
direction is 77.47° below forward, rather than exactly vertical.

| Carrier placement | Pitch delta from saved pose | Root module / pitch case | Roll shaft direction |
|---|---:|---|---|
| Current | 0° | Clear at sample | 12.53° from horizontal |
| 45° down, rearward | +57.53° | Clear at sample | 45° from horizontal |
| Horizontal, rearward | +102.53° | Clear at sample | Vertical |
| 45° down, forward | −32.47° | Carrier intersects both | 45° from horizontal |
| Horizontal, forward | −77.47° | Carrier intersects both | Vertical |

The rearward 45° placement also clears those root obstacles at pitch offsets
−20°, −10°, 0°, +10° and +20° around it. These five samples are recorded in
the JSON; the intervening motion has not been checked continuously.

It is a candidate for further design, not a selected rest pose.
Tilting the complete carrier changes the roll shaft direction and
the direction of the current thigh. A horizontal carrier makes B's axis
vertical; retaining a downward thigh would then give rotation around that
vertical axis. A diagonal carrier requires the thigh, ground contacts and
useful lateral motion to be re-derived together.

The intersections use the exact current carrier, root module and imported
servo references. The side projections can overlap when the solids are
laterally separated. Clear samples do not establish continuous travel, a
complete leg, fastener/tool access, cables, strength or walking. The thigh is
shown only as a direction line, not as accepted geometry in these placements.

Turning only B's body/socket around B's shaft would preserve the axes and is
a different option. Isolated socket/body placements turned outwards by 0°,
45° and 90° about B from the current orientation clear the root and pitch
case at the saved pose, but a connecting carrier has not
been designed or checked for those orientations.

No production orientation or saved pose was changed by this study. The viewer
contains the DEC-56 narrowing, bevels and fillets in the DEC-55 orientation;
its remaining travel limitations are recorded in [OQ-22](../../open-questions.md).

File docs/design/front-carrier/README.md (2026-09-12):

# Front carrier — flat-back study

2026-09-10. **Historical candidate snapshot, now superseded by DEC-49/50 production CAD.**
The common flat-back approach is implemented without the historical bevel in
`root_carrier_left/right`, two of each hand at front and rear; current status and exports are linked from
the [part review](../../part-design-review.md).

[Comparison PNG](comparison.png) · [Candidate STEP](flat-back-candidate.step) ·
[Candidate STL](flat-back-candidate.stl) ·
[Current print orientation STL](current-print-orientation.stl) ·
[Measured results and clearance scope](study.json).

The candidate fills the 8.115 mm bridge-to-socket step to provide a shared
flat back. Its head-facing chamfer preserves clearance at the six sampled
pose/pitch combinations. Joint interfaces and centres are unchanged. Bed
contact is 1,797 mm² versus 575 mm²; print height is 50.5 mm versus 88.1 mm.
The current and candidate STLs use their respective print orientations.
Place the minimum Z face on the bed; no packed plate or sliced file is supplied.

This is a valid single solid with a watertight mesh, not a successful print.
Six added-material collision checks do not establish full joint travel,
tool access or strength. Resolve the revised enclosing socket and inspect
layers before integrating the candidate into production CAD.

The study images and measurements are retained unchanged. Use the production
exporter for the revised parts; the superseded candidate builder is retired.

Koala-derived study geometry: CERN-OHL-S-2.0, as the production source.

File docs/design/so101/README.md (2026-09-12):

# SO-101 socket and fork construction templates

[Photo supplied by the maintainer](IMG_7004.png) ·
[Template comparison PNG](template-comparison.png) ·
[Current-part inventory PNG](current-parts-review.png) ·
[Unequal drive/idler slot views](socket-slot-comparison.png) ·
[Slot measurements](socket-slots.json) ·
[Full engineering critique](../../part-design-review.md).

| Extract | Exact source geometry | Purpose |
|---|---|---|
| Enclosed servo-base socket | [STEP](upper_socket_source.step) · [STL](upper_socket_source.stl) | Floor, enclosing walls, entry reliefs, stepped pocket and ear-screw seats |
| Robust horn fork and root | [STEP](upper_fork_source.step) · [STL](upper_fork_source.stl) | Connected broad cheeks, rounded tips, root web and horn-hole details |

These are **reference templates**, not finished koala prints. Cropping isolates
regions of the source part; the cut planes are not proposed assembly seams.
No socket dimension, screw hole, fillet or load-bearing feature was resized.
The source geometry needs adaptation to the measured koala hardware stack,
compact clearance envelope and each part's print orientation.

Source: `Upper_arm_SO101.step`, TheRobotStudio/SO-ARM100,
[commit eecbe3e0a9ebb23e25ad7b2759b03884c6660903](https://github.com/TheRobotStudio/SO-ARM100/blob/eecbe3e0a9ebb23e25ad7b2759b03884c6660903/STEP/SO101/Upper_arm_SO101.step).
Its SHA-256 is
`efa19a6dd2ccb459248500c76629cfa840630e7e15d9e146394d31da1525dd61`;
the neighbouring checkout and our vendored copy match exactly.

The original STEP and derived STEP/STL geometry are **Apache-2.0**, copyright
the upstream contributors; [licence](../../../LICENSES/Apache-2.0.txt).
Changes to the derived assets are limited to clipping and rigid transforms.
The original remains unmodified in `hardware/vendor/so-arm100/SO101/`.
The photo is the maintainer's `../IMG_7004.HEIC`, converted to PNG for viewing.

## Coordinates and regeneration

Socket template: X is the output-axis direction, Y is case width and Z points
from servo Bottom to Top. The nominal pocket floor contact is Z=0. Fork
template: output axis is X, horn centre is the origin, and +Z points towards
the connecting body. The original flat print face is native STEP Y=0, with
+Y as build direction. These are distinct reference frames, recorded in
[template-study.json](template-study.json) along with crop planes, measured
features and the complete current-part orientation inventory.

From `hardware/`:

```sh
uv run python -m koala_hardware.so101_templates
```

This writes only the study assets in `docs/design/so101/`. It does not replace
production geometry, regenerate the printed BOM, or operate a slicer/printer.

## Two-piece socket and paired-root access — DEC-45

[Split-socket image](split-socket-reference.png) ·
[Root access evidence](root-access-study.json) ·
[Engineering assessment](../../root-servo-mounts.md).

- [Under-arm socket STEP](under_socket_source.step) / [STL](under_socket_source.stl):
  cropped from the original `Under_arm_SO101.step` at native X = −24.85 mm.
- [Wrist-holder STEP](wrist_holder_source.step) / [STL](wrist_holder_source.stl):
  the complete `Motor_holder_SO101_Wrist` shape, without resizing.

Both retain native upstream coordinates and the Apache-2.0 licence above.
The newly vendored wrist holder comes from the same pinned commit; its source
hash and provenance, plus both extract validations, are in `root-access-study.json`.
The displayed separation is illustrative, not a proven installation path.
These are references for a revised mount, not new production parts.

Regenerate from `hardware/` with:

```sh
uv run python -m koala_hardware.root_socket_access
```

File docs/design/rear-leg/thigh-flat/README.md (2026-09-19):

# Thigh option 3 — one piece, tapered, printed on the cup-floor plane (owner, 2026-09-19)

**Adopted the same day as production `thigh` v2 and `shank` v2** with a rounding pass and
DEC-60's hip spacing (which makes the shank's flush face fall out of the geometry); see the
revision log in `cad-integrated-design.md` and `part-design-review.md`. **Slice the production
exports**, `hardware/build/stl/thigh_{left,right}.stl` and `shank_{left,right}.stl` (v2, already
in their print orientations), not the study STLs named below. What follows is the study as it
was reviewed.

The owner's choice after seeing [options 1 and 2](../thigh-options/README.md) in the
viewer: keep the DEC-58 thigh as **one print**, take option 2's body form (the
idler-side cheek thickened out to the cup-floor plane so cheek and cup floor share
the bed), keep the drive-side cheek in the same part, and replace the step from the
thick cheek to the idler pad with **one flat taper along the owner's red line**
(marked on a viewer screenshot of the option 2 body). Print it on that plane with
**tree (organic) support** under the drive-side cheek and both pads; the owner knows
from SO-ARM101 that tree support works on this printer.

Geometry: `links.rear_thigh_flat`, spec `option_thigh_flat`, parameter
`THIGH_CHAMFER_Z` (27.5 mm). The taper is tangent to the idler pad's outer top edge
and to the join's outer face and reaches the cheek's outer face 27.5 mm down the
link, so pad, join and cheek read as one surface. Volume 46.2 cm³ (+4.7 on DEC-58).
Joint centres, pads, cup, knee clocking, window, the 45° root mount and the
straight servo insertion are unchanged. Both legs use it in the rear-leg viewer
(`uv run python -m koala_hardware.rear_leg_review --thigh-flat`).

Print orientation `Rot(X=-90)`: bed contact 1986 mm², height 73 mm, geometry
screen ≈57 cm³ of support ([screen](../thigh-options/print-orientations.png),
bottom row); tree support will use less and is the owner's call. The taper face
itself is a 67° overhang on the bed side. STLs in the print orientation:
`hardware/build/rear-leg-review/thigh_flat_{left,right}.stl` (SHA-256 a3ba9056 R,
7b69bf15 L, 2026-09-19 export). **Slicing waits for the printer**: plate 1 (root
sockets) is printing and nothing is sliced on printhub during a print
(3d-printing rule 1). Slice one part at a time with the Flathub 2.9.6 slicer
(organic support; its `--merge` crashes, single parts are fine) and the
`petg_fig_tree`-style organic settings plus koala's 4 perimeters / 30 % gyroid or
grid — settings to be fixed when sliced and recorded in `test-log.md`.

## Shank: motor moved inboard 2.25 mm (owner, 2026-09-19)

The DEC-58 shank prints on its outer face, but that face has a 2.25 mm step:
the motor-mount face stands proud of the drive fork's outer face, so the fork
pads sit in a recess. The owner asked for the motors to move inboard by that
step. `SHANK_MOTOR_INSET` (2.25, derived) does that in `links.motor_shank` and
`motor_face`; spec `option_shank_flush`. The outer face is now one plane:
bed contact 1821 → 2612 mm², overhang 2241 → 1457 mm², height 51 → 49 mm,
volume 36.5 cm³ (the outer step and its R2 return disappear). STLs:
`hardware/build/rear-leg-review/shank_flush_{left,right}.stl` (SHA-256 7288b0da R,
505c949a L). **Consequences:** the bought motor stack moves with the face, so the
rear wheel track narrows from **220 to 215.5 mm** and the neutral motor end gap
from 36 to 31.5 mm; the inward-roll stop is motor against motor, so it moves
too: **−5.5° → −4.5° in quadruped and −5° → −4.25° upright** (review of 2026-09-19 with the flush shank on both legs; every other check unchanged and passing, `flush_motor_insertion_*` and `flush_motor_driver_*` in `clearance.json` at 0). The main assembly keeps 220 mm
until the owner adopts this; the review carries it on both legs with the moved
motors, hubs, wheels and screw heads.

## Checks

Run 2026-09-19, both legs option 3, all passing: roll −30..30° every degree
against the carrier and B's cases; knee 0..120° every degree against the shank;
horn bores, heads and drivers on both pads; knee ear access; straight C insertion
(0/5/15/25/50 mm); motor insertion; all 16 assembly samples clear; every viewer
endpoint and both combined samples clear in solid CAD (`viewer-endpoints.json`,
`all_passed: true`). Sampled travel identical to the DEC-58 rear-leg viewer on
every axis in both poses except inward roll, which the moved motors reduce by 1° and 0.75° (above). Screenshots (with the flush shank): [quadruped](viewer-quadruped.png) ·
[upright](viewer-upright.png) · [parts tab](viewer-parts.png). These are CAD
clearances, not walking limits; nothing is sliced or printed.

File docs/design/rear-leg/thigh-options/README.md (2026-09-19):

# Thigh print-form options — 2026-09-19 review

Two ways to make the DEC-58 rear thigh printable, modelled side by side for the
owner to judge in the [rear-leg viewer](https://blake.tail13a0c0.ts.net:8443/rear-leg/)
(Tailscale; rebuilt with `uv run python -m koala_hardware.rear_leg_review --thigh-options`).
**Left leg = option 1, right leg = option 2.** Screenshots: [quadruped](viewer-quadruped.png) · [upright](viewer-upright.png) · [parts tab](viewer-parts.png). Everything else is DEC-57/58: joint
centres, 85/90 mm links, pads, cup, knee clocking, the yoke window and the
45° root mount. The main assembly, BOM and the DEC-58 exports are untouched;
`rear_leg_review` without the flag rebuilds the DEC-58 viewer.

Why: the DEC-58 thigh is a C-yoke whose parallel cheeks are 50 mm cantilevers in
every lying orientation, and its knee pocket opens toward the bed
([orientation study](../thigh-orientation-study.png), owner review 2026-09-18).
The socket cannot be centred under the bridge (the shaft fixes it) and a wedge
under the bridge would occupy the case's own space, so both options change the
knee end instead. [Print-orientation screen](print-orientations.png).

## Option 1 — one print, closed knee-end frame (left leg)

`thigh_frame`, `links.rear_thigh_frame`. A **4 mm foot** runs from the bridge down
to the cup's return plane on the drive-pad side and a **1.7 mm bar** runs along
that plane to the cup wall, 0.3 mm off the case's Side face
(`THIGH_FOOT_T`, `THIGH_BAR_CLEAR`). The part **stands on the knee socket**: both
cheeks and both pads are vertical, bed contact 1718 mm², height 110 mm. What is
left to print: one **45.9 mm span** bridged under the bridge across the empty case
space (2 mm above where the case will sit) and the horn-bore roofs. The screen
counts that span as ≈45 cm³ of support because it cannot see bridging; if the
slicer bridges it, support is near zero, otherwise it is one block open from
both X sides. Volume 44.7 cm³ (+3.2 on DEC-58).

Consequences: servo C cannot slide straight out past the foot, so it enters
**sideways (X) at its 17 mm pre-insertion offset**, 1.65 mm clear of the foot,
then slides into the pocket; checked in `clearance.json`
(`frame_C_sideways_*`). Layers lie across the cheeks' bending load. Strength,
bridging quality and support removal are unverified.

## Option 2 — two prints, bolted cheek (right leg)

`thigh_body` + `thigh_cheek`, `links.rear_thigh_split`. The drive-side cheek,
with its pad, join and the bridge end, is a **separate piece** with a **5 mm lip**
over the bridge's knee-end face. It mates on an L (cheek inner face against the
bridge end, lip on the bridge's outer face) with **two M3 into captive nuts**
entered from the window face: one along Z through the lip
(`THIGH_LIP_SCREW_Y`), one along Y through the cheek with its head counterbored
flush (`THIGH_END_SCREW_Z`, `THIGH_END_NUT_Y`). The body's idler-side cheek is
**thickened out to the cup-floor plane** so the body lies flat on that plane:
bed 2258 mm², height 67 mm, ≈10 cm³ of support (one block under the idler
pad's free part). The cheek piece lies on its outer face: bed 1013 mm², height
20 mm, ≈2.5 cm³ under the drive pad. Volumes 38.6 + 9.7 cm³.

Consequences: servo C is fitted **before** the cheek piece, so the straight
insertion path is unchanged. The drive-horn torque passes through two M3 and
the L faces: unverified. An earlier variant with a 5 mm outer lap plate
**failed the 0–120° knee check at 117°** (shank against the plate, 3.1 mm³);
the lip-only joint stays inside the DEC-58 envelope and passes. The screw
heads sit on the lip and in the counterbore only.

## Results, 2026-09-19

All checks below pass for both options in the same run. The viewer's sampled
travel is **identical to the DEC-58 rear-leg viewer** on every axis in both
poses (quadruped pitch −51..173.75°, roll −5.5..180°, knee −96.5..56.25°;
upright pitch −125.5..99.5°, roll −5..180°, knee −91.25..61.5°); the knee
stop on the right leg now names the cheek piece alongside the body. Every
endpoint and both combined samples clear in solid CAD
(`viewer-endpoints.json`, `all_passed: true`). The frame's bar needed
`THIGH_BAR_CLEAR` (0.3 mm) because a bar lying exactly on the case's Side
plane registered the reference case's ~0.05 mm oversize outside the allowed
pocket-contact zone. Viewer engine change (`mechanical_limits.js`,
`viewer.py`): a servo's exempt contact partner may now be a list, so a fork
split across two prints keeps its designed horn contact exempt; the main
viewer was rebuilt against the new engine hash with unchanged limits.

## Checks (`clearance.json`, `viewer-limits.json`, `viewer-endpoints.json`)

Local, every degree, both options and the fixings: roll −30..30 against the
carrier and B's cases; knee 0..120 against the shank. Horn bores, heads and
drivers on every pad; knee ear access; C insertion (straight for the body,
sideways then straight for the frame); motor insertion. Assembly samples and
the viewer's sampled travel with both legs, all rear hardware and the 45°
mount. These are CAD clearances, not walking limits. Nothing is sliced or
printed; both options are `unknown` printable until one is chosen and printed.

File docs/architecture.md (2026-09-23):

# Architecture — the "nervous system"

Two-tier compute, split by the reflex-vs-intent boundary.

## Compute tiers

| Tier | Hardware | Role | Rule |
|---|---|---|---|
| **Spinal cord** | real-time MCU (Teensy 4.0 leading; ESP32 / RP2040 candidates) | motor/servo output, IMU read, **the balance loop**, encoders, safety | fast (~200-1000 Hz), deterministic |
| **Cerebrum** | Raspberry Pi 5 + ROS2 | perception, SLAM, mission/behaviour, LLM "personality", networking | not real-time |

### The load-bearing rule

**The balance loop lives on the MCU - never on the Pi.** Linux isn't real-time and
ROS2-over-USB adds jitter that destabilises an inverted pendulum. IMU -> PID -> wheel
output closes on the MCU; the Pi only sends setpoints and reads telemetry.

### Bridge & contract

- **micro-ROS** on the MCU makes it a native ROS2 node (DDS-XRCE over serial). It runs
  against a **micro-ROS Agent** process on the Pi, which bridges XRCE into the real DDS
  graph; the MCU then appears in `ros2 topic list` like any other node. Full explanation,
  shared with the rest of the family:
  [wk-robotics/docs/common.md](https://github.com/WayneKennedy/wk-robotics/blob/main/docs/common.md#micro-ros-how-the-mcu-joins-the-graph).
- **Board support caveat — [OQ-14](open-questions.md).** micro-ROS upstream has **not
  tested the Teensy 4.0** that DEC-18 selected and bought, while listing the 4.1 as
  Supported. The board table, the checked date and the reason it is nonetheless expected
  to work are family facts and live once, upstream:
  [wk-robotics/docs/common.md](https://github.com/WayneKennedy/wk-robotics/blob/main/docs/common.md#micro-ros-how-the-mcu-joins-the-graph).
  What is koala's alone: **DEC-04 makes this bridge load-bearing**, so close it cheaply
  — flash a micro-ROS example to the 4.0 before firmware is written around it. If it
  fails, the fallback is a 4.1 or the ESP32 already named above, not a redesign.
- The **topic contract is the shared-brain backbone** of the family - fix it once and
  every member inherits it: `/cmd_vel`, `/joint_commands`, `/imu`, `/joint_states`,
  `/wheel_odom`, `/telemetry`. Bodies change; the spinal-cord protocol does not.

## Actuation map

| Joint group | Actuator | Why |
|---|---|-----|
| Limbs (hip, knee, shoulder, elbow) | Feetech **STS3215** 12V bus servo (~30 kg.cm, feedback) | load-bearing; feedback for coordinated/balance motion; one serial bus |
| Head / neck (3-RPS) | **Feetech STS3032M** (6V, 4.5 kg.cm, STS-protocol bus, feedback) + CF pushrods | small feedback servo on its own 6V bus; servos mount at the shoulder girdle, head stays light. **Fixed single cable per servo** — the 6V bus chains through the supplied 3-port connector boards and link cable, one board per servo lead, not servo-to-servo (`test-log.md` 2026-09-12) |
| Rear ankle wheels (DEC-43; fitted after walking, DEC-62) | **12V geared DC** (37D-class) + encoder | continuous rotation + torque |
| TPU feet (DEC-43/62) | Fixed rounded contacts; no ankle actuator | all four limbs in the first walking build; front pair in the wheeled build |
| *(climber, later)* grippers / winch / clutch | mixed (see backlog) | passive-latch hang, ballistic swing, winch haul |

Head mass is a hard budget (< ~250-300 g) so micro servos suffice; offload eye
expression to **screen/OLED "eyes"** rather than eye-servos where possible.

DEC-43 needs **two motor channels and two encoder inputs** for the bought
rear ankle-drive pair. The dual-channel shield covers that count and is in
hand (DEC-51 dissolved the loan to wk-devastator). Front feet support the
robot with the rear wheel contacts, then lift for balanced driving. Establish
power/thermal duty for body support and contact transfer on the assembled robot.
DEC-62's initial quadruped walking build omits the rear drive hardware and
uses the same twelve limb servos with interchangeable footed shanks. Motor
bring-up and balance follow walking; the two-tier architecture is retained.

## Power

- Single **~12 V rail (3S LiPo)** feeds both the 12V motors and the 12V servos
  (unified - no separate 7.4V servo buck). **3S only**: a full 3S is 12.6 V (within the
  STS3215 12V rating); a 4S (16.8 V) would destroy the servos.
- **5 V buck** for the Pi 5, sized generously; the Pi 5 is power-hungry and brown-outs
  are a known failure mode. Keep motor/servo current off the Pi rail.

### Power integrity (DEC-20)

**The four rules, their InMoov origin and the underlying mechanism live once, in
[wk-robotics](https://github.com/WayneKennedy/wk-robotics/blob/main/docs/common.md#power-integrity)**
- prototype from a stiff LiPo rather than a bench PSU, isolate the logic rail, bulk caps
across the servo/motor bus, fuse the pack lead. They are not restated here: this copy had
already drifted from the canonical one by 2026-09-07. **DEC-20** is koala-bot's commitment
to them.

What is koala-bot's alone:
- The **fuse pairs with the child-safe enclosure** (OQ-10).
- The single 12 V rail above puts servo and motor transients on **one bus**, so the bulk
  capacitance is load-bearing here rather than belt-and-braces.
- Per-servo current figures for sizing that fuse are in the same family document
  ([Actuators](https://github.com/WayneKennedy/wk-robotics/blob/main/docs/common.md#actuators)):
  twelve STS3215 stalled (DEC-31's count) is **~32 A** at the 2.7 A per-servo figure.

## Compute placement

Camera-eyes are **CSI** (short ribbon) so a Pi must sit near them. Clean split:
**Pi 5 in/near the head** for vision + brain; **MCU in the body** for servos - the same
head/body split as the two tiers.

## Modelling & tooling

- **URDF + RViz** - serial kinematics (limbs, base-yaw, head); the file the robot's ROS2
  stack uses. Drag joints with `joint_state_publisher_gui`.
- **CAD motion study** (Onshape / FreeCAD / Fusion) - for the **parallel** torso & neck:
  *URDF cannot represent closed kinematic loops*, so parallel mechanisms are modelled in
  CAD (workspace, collisions, singularities) or a loop-capable sim.
- **Physics** - Gazebo (ROS2-native) or PyBullet / MuJoCo for balance & gait.
  **MuJoCo, started 2026-09-23:** `hardware/src/koala_hardware/mjcf.py` writes
  `hardware/sim/koala_walking.xml`, the four-foot build (DEC-62) at the CAD's joint centres and axes:
  one visual mesh per rigid body (its prints unioned with its servo cases at the CAD socket frames,
  `hardware/sim/meshes/`), per-body mass, CoM and inertia tensor from the BREP solids, four sphere
  feet and a torso box as the only contacts, twelve position actuators. Prints weigh what the slicer
  estimated where `docs/bom.md`'s hash-matched slice exists, else solid PETG/TPU (an upper bound);
  each servo is a 55 g box. 1.51 kg, no battery or electronics (`--crude` keeps the capsule visuals
  with the same inertia). Placeholders, each labelled in the file: joint ranges (the viewer's
  shared-slider clearance bounds, not per-joint or servo limits) and Open Duck's 7.4 V servo fit.
  `mjcf_check.py` (MuJoCo 3.14, 2026-09-23): loads, CoM inside the foot polygon, stands 3 s under
  zero control. The route to a policy — the 12 V actuator model, a Playground environment — is the family
  thread in [wk-robotics `docs/status.md`](https://github.com/WayneKennedy/wk-robotics/blob/main/docs/status.md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).

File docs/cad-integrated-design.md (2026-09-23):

# Integrated chassis — current CAD and acceptance scope

**2026-09-21: interchangeable footed rear shanks for the first walking build
(DEC-62).** `foot_shank` v1 fits the existing knees and accepts the unchanged
front TPU pad. The wheeled `shank` v2 remains available. See the
[walking build, files and checks](design/walking/README.md).

**2026-09-19: recessed roll-first shoulders and front limbs derived from the rear
printability work.** This is an **unprinted revision**, recorded below rather
than banked as a decision. The torso extends around the shoulder A servos;
removable cassettes preserve bench access to the unchanged, physically proven
`root_socket` v1. Front shoulders now implement **roll → pitch → elbow**;
rear hips retain **pitch → roll → knee** and the DEC-61 inclined rear mount.

The chassis uses **28 physical prints walking / 26 wheeled**, from
**19 designs / 28 handed export variants** including six coupons and both
rear-shank alternatives. Changed torso, shoulder cassettes,
front links and corrected thigh are `unknown` printable. Root socket v1 is
`proven` with its recorded ear-hole support caveat; unchanged hip carrier v1
and shank v2 retain their recorded `assumed` status.
[Per-part versions and print approaches](part-design-review.md) ·
[Front revision, images and local clearance evidence](design/front-redesign/README.md).

## Geometry and part boundaries

- **Torso v5:** the hip-to-shoulder axis separation stays **150 mm**. Its cage
  now reaches body Z = **183.5 mm** around shoulder A; the side envelope is
  Y = ±47 mm. Dorsal rails remain at X = −46…−36 mm and taper laterally
  from Y = ±43 to ±29 mm over Z = 106…122 mm, opening the shoulder roll
  sweep. Ventral rails step from X = 10…20 to 26…36 mm below the shoulders. The body frame uses X dorsal
  negative, Y lateral and Z along the spine.
- **Recessed shoulders:** A roll centres are **110.23 mm apart**. The enclosing
  socket lips sit at Y = ±37 mm, **10 mm inside** the torso's ±47 mm side
  envelope. This measurement describes the socket lip: the servo's output
  region, horns and moving carrier still project outside it. It is an open
  structural cage, not a flush cosmetic shoulder skin.
- **Independent `shoulder_mount` v1 cassettes:** each carries one root socket
  on its original four M3×16 screws. Fit those on the bench, then mount the
  cassette through the front of the torso with four M3×20 screws into captive
  nuts. Broad flange contact and an R1.5 internal root connect the recessed
  module to the ventral frame. Either side removes independently.
- **`shoulder_carrier` v3:** the A fork and enclosing B socket share one broad
  print plane. B is **40 mm outboard of A**, placing the pitch centres
  **190.23 mm apart**. R6.3 fork roots and straight inner-ear driver tunnels
  preserve access without a hidden support chamber.
- **`upper_arm` v2:** **70 mm** pitch-to-elbow centres, with parallel B/C shafts,
  an enclosing elbow pocket and thickened cup wall coplanar with the outer
  drive fork face. R6.3 fork roots and R2 outer rounding follow the rear
  lessons. Seven short/narrow junction edges reject R2 and are explicitly
  reported as sharp; fitting faces and the accepted servo interface remain.
- **`forearm` v2:** **100 mm** elbow-to-contact reach (75 + 25 mm), a longer open
  elbow fork, R6.3 roots, an R3-rounded taper and a broad flat native −Y print
  face. The existing keyed **Ø32 mm TPU pad**, captive nut and recessed
  M3×20 screw/washer interface remain; no wrist joint is added.
- **Rear:** 85 mm thighs, 90 mm shanks, two bought 37D ankle drives and
  **220 mm track** remain. Hip pitch centres stay **52.5 mm apart** (DEC-60).
  Thigh v3 fixes the rounding implementation without changing joint datums;
  shank v2 retains its flush motor/fork print face. The rear pitch sockets
  mount on the retained **45° plate** (DEC-61). Torso v5 adds Ø6.6 clearance
  corridors through the retained flange for straight Ø6 rear screw drivers.
- **Walking rear alternative:** `foot_shank` v1 retains 90 mm from knee to
  contact centre and uses `front_contact_pad` v1, with no drive motor, shaft,
  hub or wheel. The pads sit on the shanks' centreline: **132.6 mm rear contact
  spacing** at neutral roll. The 220 mm track applies to wheels. Both
  configurations use the same knee horns and upper chassis; exchange the
  complete shanks, then select/calibrate the matching kinematics and mass model.
- **Neck provision:** a dorsal shoulder-cap slot and four generic M3 mounting
  points reserve a removable cartridge for the **three small bought STS3032M**
  servos. Published small-case envelopes are shown; purchased M dimensions,
  fixed-lead boards, retention and 3-RPS linkage geometry remain unverified.
  [Source dimensions, interface and limits](design/neck-provision.md).

The unchanged electronics tray and four spacers remain. The two new shoulder
cassettes account for the increase from 24 to 26 chassis prints. The neck
reference envelopes are neither printed parts nor an accepted head installation.

## Poses, axes and silhouette

The separate **walking** reference keeps the supported torso/front limb pose
and rear contact X = −55 mm, but lowers the rear ball centres to Z = 16 mm
and re-solves the knees for 85/90 mm links. All four TPU contacts meet Z = 0.
This is a standing CAD reference for training, not a demonstrated walking gait.
The two wheeled poses below remain unchanged.

The supported reference retains front contact centres at X/Z = **205/16 mm**
and rear wheels at **−55/40 mm**. With unrolled shoulders, front contact spacing
now follows the **190.23 mm** pitch spacing; rear track remains 220 mm and
longitudinal contact spacing 260 mm. Upright, the front contacts retain the
100 mm forward / 330 mm high reference. These are inspection poses, not a
loaded transition or controller targets. The **450 mm upright head-top** figure
remains a sizing allocation.

Front A rotates about the torso's longitudinal axis. Its downstream B pitch
joint and elbow follow that rotation; pitch and elbow axes remain parallel.
Rear A instead rotates about the lateral pitch axis and carries B roll.
The assembly and viewer therefore use different transform orders for the two
limb pairs. Their left/right halves remain mirrored. The optional sideways
"hug elbow" is not implemented; the current sagittal elbow preserves supported
foreleg shortening, with the alternative still tracked in OQ-25.

The torso and cassette multi-view review finds a compact cage, broad rails,
a shallow chest step and inward socket flanges, with no outriggers or disconnected
features: **an acceptable structural prototype**. V5's inward dorsal taper
narrows the upper back without adding depth or a backpack. Front parts pass their
individual visual review. [Assembled views](design/front-redesign/body-views.png)
also retain compact depth, with front shoulder span near the rear wheel span
and deliberate front/rear differences. The head is still a sizing allocation;
this is structural-prototype review, not a finished shell or gesture acceptance.

## Corrected servo interface

`servo_iface.py` uses the confirmed Gauge_0 **34.9 × 24.7 mm** pocket. The
four-ear saddle bosses reach the **31.8 mm** ear planes (+16.4/−15.4 in the
pocket frame), outside the centred widest case pads. M2 hole positions are
±10.25 mm laterally, 2.25 mm Back and 5.8 mm Front above the Bottom.
DEC-50 follows the pinned SO-101 socket: the drive slot is 14 mm wide from
the floor; the idler slot is 18.5 mm wide from 5 mm above the floor. Its
continuous lower seat separates the low M2 bores from the slot boundary,
removing the earlier tangency and the need for a widened relief. Ear planes,
hole centres and the Gauge_0 gap stay unchanged.
[Dimensioned slot views](design/so101/socket-slot-comparison.png).
Each M2×5 screw bears on a **2.2 mm** plastic seat, giving **2.8 mm nominal
penetration** into the servo ear. All four screws retain the servo itself.

Both horn contact faces are flat, **36.4 mm** apart; the old Ø20.5 recess is
removed. Each horn pad has a **3.5 mm web** and **Ø6.4 × 2.8 mm** head pockets,
for 6.3 mm total thickness. The Front centre clears the supplied pan head with
a cylindrical pocket and Ø3.2 access hole; the Back has a blind boss relief.
Neither centre is a conical screw-bearing seat.

The Back M3×6 square fixings use **OD6 × 0.5 mm narrow washers**, leaving
2.0 mm nominal engagement against the measured 2.1 mm tapped idler body.
Front square fixings retain 2.5 mm engagement. Procure those washers and check
actual clamping/bottoming on the rig; the nominal arithmetic does not establish
thread strength. Heads and washers are included in the assembled CAD envelopes.

The circular fork nose is Ø20.8; the tapered roots broaden farther from the pivot. Its web ligament outside each M3 bore is
about 1.7 mm at the narrowest radial point; the outer head-pocket rim is thin.
The compact shape clears the measured Back bay nominally, but connector plug
size, tolerances, wear and fork strength need the real rig. A plugged-in loom
and its flexing service loop are not modelled as accepted hardware.

The optional imported case's stale Back centre projection is removed locally
before composing the measured boss/horn stack. The retained ≤50 mm³ reference
fit screen applies **only** to a servo and its owning saddle, and only inside
its intended pocket contact region. It does not allow moving-part interference.
The fallback stepped case is checked separately; neither reference overrides
physical measurements or the confirmed SO-101 fit.

## Fasteners and assembly

The generated [BOM fastening schedule](bom.md) is authoritative for quantities.
Candidate stacks still require real clamping, engagement and tool checks.

| Connection | Stack / access |
|---|---|
| Case ears | M2×5 through 2.2 mm seat; 2.8 mm nominal penetration |
| Drive horn square | M3×6 through 3.5 mm web; 2.5 mm engagement |
| Idler horn square | M3×6, 0.5 mm narrow washer, 3.5 mm web; 2.0 mm engagement |
| Root socket to rear torso / front cassette | Four M3×16 through 5 mm flange and the unchanged socket plate/shelf into captive nuts |
| Front cassette to torso | Four M3×20 per side, driven from the front into cassette captive nuts; Ø6 straight driver paths |
| Motor faces | Six M3×8 through 5 mm face plate; 3 mm nominal engagement, bore depth unverified |
| Hub | 5 mm plate + 3 mm cap head + 0.5 mm clearance + 9.5 mm hub = 18 mm nominal stack |
| Front TPU pads | Recessed M3×20 and washer into side-loaded captive nut; keyed location |
| Tray | M3×25 through 4 mm tray, 4 mm spacer and 10 mm frame boss; washers and nut |

1. **Preload all four M3 frame nuts into each bare front cassette before
   attaching its A root.** The fitted root blocks the straight loading path
   of the two inner nuts. Hold the nuts in place during bench assembly.
2. Drop four M3 nuts into each root socket, then install A and all four ear
   screws on the bench. For a front limb, bolt that complete root to the
   preloaded cassette with four M3×16, offer the cassette to the ventral
   crossmembers and install four front-access M3×20. For a rear limb, mount the root directly
   to the inclined flange; its driver corridors pass through the complete torso.
3. Fit B and all four ear screws to its carrier before installing the upper
   link. Fit C and all four ear screws to the upper link before the lower link.
   Insert cases Bottom-first with horns removed. Install horns/centre fixings,
   then clevis square fixings without pulling the forks inward.
4. Insert each footed lower link's captive nut before fitting the keyed TPU pad.
   For walking, fit a handed `foot_shank` at each rear knee using the same
   drive/idler horns, square screws, centre retention and idler washers as
   `shank`. For the wheeled build, install rear motors axially from inboard,
   then their face screws, hubs and wheels. Exchange whole shanks with the
   robot supported and power isolated; the knee servos stay in the thighs.

Servo replacement requires removal of its driven link. Front root service
removes the four frame screws and slides the cassette **laterally outward**
to expose its bench screws; pulling rearward eventually hits the dorsal rails.
No driver is expected to pass through the opposite A servo. Harness routing, actual plugs, retention and
child-safe guards remain detailed/physical checks.

## Manufacturing and validation

The [current validation record](design/cad-validation.json) links the final
versions, exports, slices and scoped checks.

Each changed print has a deliberate broad bed plane and externally accessible
support removal; [part review](part-design-review.md) records the details.
[Current local slices and selected layers](design/front-redesign/README.md#local-slicing-and-support-review)
cover all 11 changed handed exports, including torso v5. Inspected layers show
broad bases and trees in open forks/cups and through the torso cage. They do
not prove every layer start or physical support removal. These parts remain
`unknown` and are **not physically proven**. Existing slices apply only to
their recorded STL hashes: the sliced thigh v2 does not validate corrected
thigh v3. OQ-22 records earlier shank v2 organic slices with hashes matching
the current exports; their G-code and layers were not re-reviewed in this
session's 11-slice batch. Older manufacturing-report shank slices predate v2.

The [complete front moving-package report](design/front-redesign/driven-package-clearance.json)
checks outward-positive shoulder roll **±30° at 2° intervals**, in both saved
pitch/elbow configurations, including all moving front prints/cases/fixings
against fixed A/module/cassette hardware: 2,604 solid pairs per pose, no overlap.
The [installed-front report](design/front-redesign/installed-front-clearance.json)
checks both fronts at five roll settings against the torso, neck envelopes,
opposite front and nominal rear hardware with both case models: 20 configurations,
1,236 candidate pairs, no hits. Narrower adjacent-joint/rail checks and their
limits remain in the [front record](design/front-redesign/README.md).

For the **2026-09-19 wheeled revision**, the 65-test Python suite, 26 handed exports, two assembly STEP exports and
11 current-version review slices pass. Both complete nominal poses pass
180 checked pairs each. The [62-sample primary audit](design/front-redesign/assembly-audit.json)
and [two-pose fallback audit](design/front-redesign/assembly-audit-fallback.json)
pass. The main browser smoke test and
[all initial grouped-slider endpoints](design/front-redesign/viewer-endpoints.json)
pass (24 configurations / 1,452 pairs across both case models). The
[rear production review](design/rear-leg/README.md) also passes both browser
poses, all 12 initial bounds and four combined configurations; its exploratory
−45° quadruped pitch collision is outside the current viewer bound. The frame audit includes the actual torso in rear
driver checks and distinguishes front bench root fixings from installed
cassette fixings; service tests enforce loading cassette nuts before A.

The **2026-09-21 walking addition** brings the suite to 71 passing tests,
28 handed exports and three assembly STEP configurations. Both new shanks
have version/hash-matched local slices; nominal primary/fallback audits,
31 nearby walking samples and 12 walking viewer-endpoint checks pass.
[Walking evidence and its limits](design/walking/README.md).

The viewer uses the same serial joint orders as the assembly, samples
pose-dependent clearance in **0.25° increments**, and reserves **2°** before the
first detected collision. Hidden structure and hardware still constrain travel.
Caches are keyed by geometry and engine hashes; Node.js is needed to build them,
not to view the site. The unresolved head geometry is omitted. This finite
mesh search does not prove continuous motion, calibrated servo travel, cable
clearance, ground contact or loaded balance. Historical manufacturing/viewer
endpoint reports apply only to their own revision. Current validation outcomes
are recorded with the [front revision evidence](design/front-redesign/README.md).

Continue with support removal, fitting and load/creep on the actual parts;
head/neck, battery/electronics and loaded transitions remain OQ-17/18/21/22.
No new repeat SO-101 fit gauge is required.

## Revision log

- **2026-09-21 footed rear shank v1 — unprinted.** Implements DEC-62 with a
  separate `foot_shank`, 90 mm from knee axis to TPU ball centre. The long
  open fork retains the knee's horn span, bores, head recesses and driver
  access. The shared front lower-link construction is shortened at its taper
  and terminal seat; `forearm` v2 and `front_contact_pad` v1 geometry stay
  unchanged. No motor ring or drive hardware is included. The same pad key,
  captive nut and recessed M3×20/washer fasten the rear TPU pad.
  **Visual gate:** inspected iso, side, end and top in
  [four views](design/parts/foot_shank-views.png) before export/audit/viewer.
  Does it look stupid? **No:** it reads as the front foot's shorter counterpart,
  with a continuous tapered shaft, open knee fork and useful broad print face;
  no redundant motor bracket remains. This is assistant shape review, not
  physical acceptance. Printability starts `unknown`.

Dated notes on **unprinted** geometry, reclassified out of `decisions.md` by
DEC-59 (2026-09-18). Entries keep their original DEC numbers so existing
cross-references resolve; the full original text is in git
(`git show 82e4995:docs/decisions.md`). A note here is not accepted geometry:
it records what was tried, what triggered it, and what replaced it. An entry
leaves `unprinted` only when [`test-log.md`](test-log.md) records a print of
that revision. New CAD iterations go here, one entry each, never to
`decisions.md`.
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

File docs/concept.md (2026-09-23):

# Koala — Concept & Design Principles

## Vision

An open-source **family** of small, printable, affordable, fully-documented
companion robots. The differentiator is not novelty but **completeness**: a
coherent family sharing one "brain", each member shipped with a build video, full
BOM, and working software — the opposite of the half-finished robots that litter
model repositories.

The family is unified by a **shared brain** (common electronics + firmware + a
ROS2/topic contract, see [`architecture.md`](architecture.md)) with **swappable
bodies**. The defining split between members is **wheel-vs-gripper limb-ends**
(see [`backlog.md`](backlog.md)).

## Koala V1 — the first member

A ground-based companion with **two rear ankle wheels and two replaceable rounded TPU
front contacts**, articulating knees and a two-wheel balancing/drive mode
(DEC-31/41/43). **The first build uses four TPU feet to train quadruped walking
(DEC-62): interchangeable rear shanks omit the motors and wheels.** The
wheeled configuration remains the V1 end goal. The compact koala baseline is **450 mm upright head-top height**,
within the ~400–500 mm overall size goal (DEC-15). Head mounting and position
are unresolved; this height is a sizing allocation, not a solved installation. The supported quadruped pose
is lower. These poses are CAD references; loaded transitions and locomotion
remain to be demonstrated. Dimensions: [body-layout.md](body-layout.md).
Printable in
**PETG** with **every part <= 200x200 mm** (designing to the commonest bed
maximises who can build it, even though the reference printer is 220 mm).

### Morphology & DOF (V1)

| Segment | DOF | Actuator | Notes |
|---|-----|---|---|
| Front limbs x2 (arms *and* forelegs) | 3 each | STS3215 bus servo | shoulder **roll → pitch** → elbow (DEC-54; elbow axis direction OQ-25); flatter integrated forearm ending in a replaceable TPU contact at wrist/hand reach; support and gesture; 75 mm forearm + 25 mm hand to Ø32 mm ball centre (DEC-43) |
| Rear leg hips x2 | 2 each | STS3215 bus servo | **pitch + roll**, in that serial order (DEC-41); active lean and leg placement with a rigid torso |
| Rear knees x2 | 1 each | STS3215 bus servo | **active in V1** (DEC-31) — articulating knee between thigh and shank; with the hips it sets ride height, crouch and stand |
| Rear lower links x2 | fixed foot initially; continuous wheel spin later | Twelve limb servos retained; bought 37D drives fitted in wheeled configuration | interchangeable footed / wheeled shanks at the knee (DEC-62); rear TPU pads identical to front |
| Head / neck | 3 | micro servo + CF pushrod | **3-RPS parallel** (pitch/roll/heave); *yaw delegated to the base* |
| Torso | 0 (V1) | - | **rigid strut** in V1; interfaces pre-designed for a single 3-DOF platform later |

V1 actuator count: **12 STS3215** (6 arm + 4 hip + 2 knee; stock/acceptance — OQ-16) + **3 micro** (head) + **2 DC** in the wheeled configuration (bought pair retained, omitted from the walking build).

### Locomotion

- **Walking first:** four fixed rounded TPU contacts, with the existing three
  servo joints per limb. Train and validate quadruped walking before fitting
  wheeled shanks; ground contact, loaded gait and traction need physical evidence.
- **Supported stance:** front ball feet and rear wheel-feet provide four
  contacts. Standing without active balancing is intended; power-off standing
  is not established. Uneven-terrain stepping with wheel-feet is a later gait
  experiment, not a prerequisite for completing V1.
- **Wheeled balance/drive:** raise the forelegs and balance on the rear ankle
  wheel pair. Differential drive turns the robot; hip and knee angles set
  posture and ride height.
- **Lean:** 2-DOF leg hips bank into turns (V1); the torso platform adds torso lean
  once activated (V2).
- **Mode transition:** transfer load from supported stance to rear wheels while
  lifting front feet and establishing balance. CoM, support and servo loads
  throughout the motion remain open; there is no knee-wheel deployment mechanism.
- **No agile climbing in V1.** Rounded front feet add no grasping DOF;
  grippers and winch-assisted clambering remain later options in the backlog.

Closest prior art: **Swiss-Mile / ANYmal-on-wheels** ([`references.md`](references.md)).

## Design principles

1. **DOF budget = cost budget.** Every DOF is one servo (~£15-25 landed). Be ruthless;
   buy spares, not speculative DOF.
2. **Actuator matched to task** (heterogeneous actuation). Spend STS3215-grade money
   only where body weight and balance flow through (limbs). Head/ears/fingers -> micro
   servos; drive -> geared DC. Exploit passive dynamics where possible.
3. **Every part <= 200x200 mm.** Prefer one integrated structural print per link
   (DEC-39), with an explicit print orientation. Add a seam only for a specific
   assembly, service, strength or bed-size reason; any seam remains a designed
   joint derived from the master model.
   Bed fit is enforced by the CAD build. Support-free manufacture remains a
   preference, with accessible local supports allowed. Sliced-layer and physical
   validation remain necessary; the surface-area
   screen alone does not prove it (DEC-29).
4. **Body-as-source-code.** Parametric code-CAD (`build123d` / `CadQuery`) so `bed_size`
   and `scale` are parameters, geometry lives in-repo, and it can export URDF.
5. **Finish V1 end-to-end before the family** — design -> print -> BOM -> firmware ->
   app -> docs -> one video.
6. **Mechanical honesty** (banked from an InMoov build): no plastic-on-plastic sliding
   threads; real bearings, rotary-servo + pushrod linkages, or metal leadscrews;
   low-friction spherical bearings; a *virtual* pivot via a parallel mechanism where
   it earns its keep.
7. **Child-safe by design.** The audience is young children (2-5). No pinch points at
   joints/linkages; software speed & torque caps + e-stop; graceful (gentle) falls; a
   protected/enclosed LiPo; no small detachable / choke-hazard parts; rounded edges; no
   hot exposed surfaces. Specifics tracked in [`open-questions.md`](open-questions.md) (OQ-10).

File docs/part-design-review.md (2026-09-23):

# Part construction and printability

Current 2026-09-19 revision: recessed **roll → pitch** front shoulders, parallel
pitch/elbow front links and the retained **pitch → roll** rear legs. Broad print
faces, enclosing sockets, open forks, filleted roots and accessible support
removal carry the rear redesign lessons into the front limbs.
[Design and assembly](cad-integrated-design.md) ·
[Front revision and views](design/front-redesign/README.md) ·
[Current slices](design/front-redesign/README.md#local-slicing-and-support-review) ·
[Earlier manufacturing records](design/manufacturing/README.md).

## Printability tags — DEC-47

Every printed design has a monotonically increasing version in
[`part-versions.json`](../hardware/part-versions.json), shown in the generated
BOM. Geometry changes require a version bump and reassessment. A `proven` tag
belongs to the version actually printed; earlier slices and prints do not
transfer automatically.

- `unknown`: the current revision has not established a reviewed manufacturing
  outcome; bed contact, layer starts or support removal still need validation.
- `assumed`: a credible print approach is recorded, without a successful
  physical print of that version. A surface-area screen alone is insufficient.
- `proven`: a physical print of that version is recorded in [the test log](test-log.md),
  with its relevant settings and limitations.

There are **19 designs / 28 handed export variants**, including six coupons
and both rear-shank alternatives. The chassis uses **28 physical prints walking
/ 26 wheeled**. **Root socket v1 alone is proven**;
the new/changed parts below remain `unknown`. The unchanged hip carriers have
plate 2 slices; no physical result is recorded here. OQ-22 records earlier
shank v2 organic slices with hashes matching the current exports; they were
not re-reviewed in this session's 11-slice batch. Sliced thigh v2 is superseded
by v3.

## Current structural parts

The table identifies the declared bed face, not a claim of support-free printing.
[Current local slices](design/front-redesign/README.md#local-slicing-and-support-review)
cover all 11 final changed handed exports, including carrier v3 and torso v5,
with matching STL hashes and inspected selected layers. They do not prove every layer start, physical support removal or fit.
STLs already carry the declared orientation. PETG support must grow from the bed only;
review layer starts and removal access before printing. TPU uses no support.
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

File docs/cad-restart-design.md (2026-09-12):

# DEC-34 lower-body prototype — 2026-09-07

**Historical: implementation replaced by [DEC-40](cad-integrated-design.md).**

**Morphology superseded by DEC-36/37.** This is the historical specimen's
implementation record. Use [body-layout.md](body-layout.md) and
[the engineering schematics](design/README.md) for the adopted short-limbed,
four-wheel body and resolved dimensions.
DEC-39 also supersedes the flat-cheek/crossbar decomposition described here;
use [integrated-links.md](integrated-links.md) for the new structural strategy.

**2026-09-08 status: correction required.** The [measurement impact assessment](cad-measurement-impact.md)
supersedes the socket's earlier acceptance and records the current audit failure.
This document describes the former implementation and design intent; its
socket geometry and fastening assumptions below are not a build-ready design.
For whole-body height, skeleton correspondence and the static viewer's side
backdrop, see [body-layout.md](body-layout.md).

Replacement build123d geometry for DEC-30/31. **Digital prototype; no new part
has been sliced, printed, fitted or load-tested.** The confirmed SO-101 fit
(DEC-33) is the input, not acceptance of these new parts. Start physical work
with the five `coupon_socket_*` parts and one real servo.
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

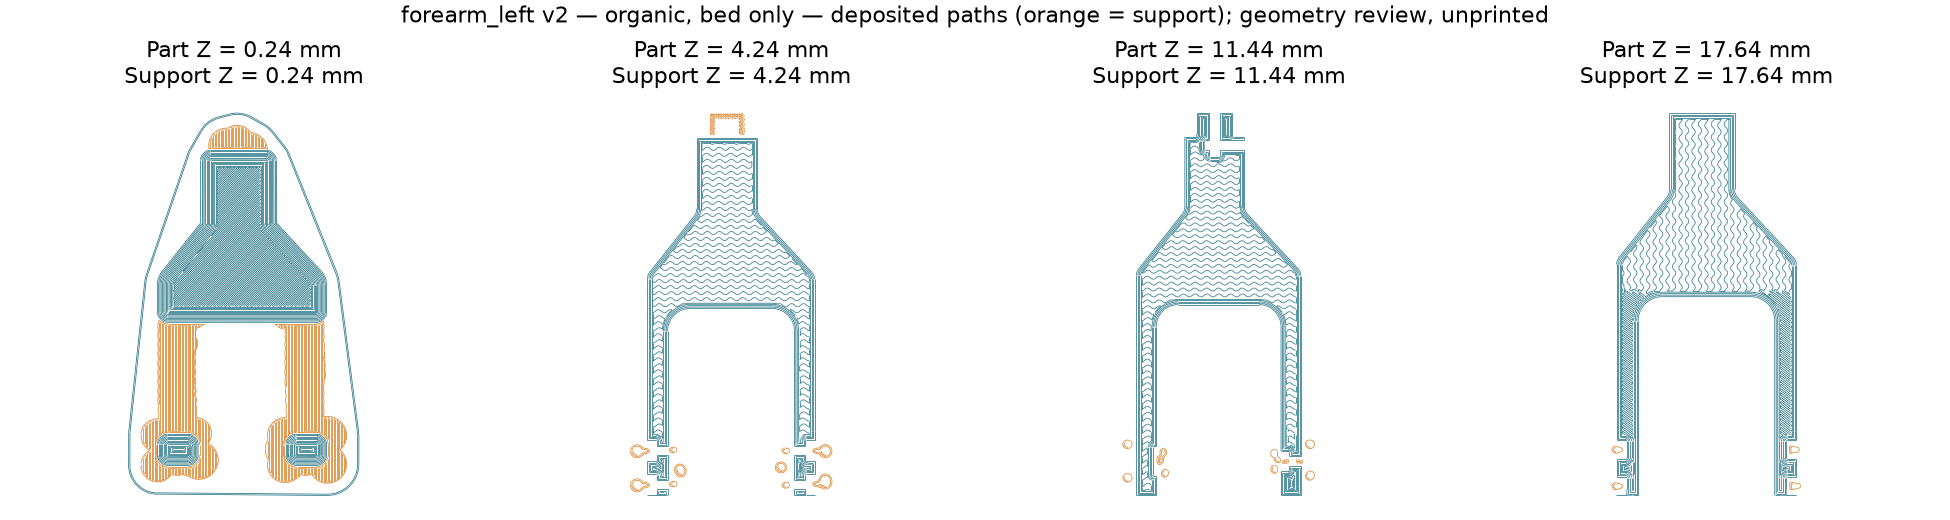
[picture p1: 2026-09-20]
docs/design/front-redesign/forearm_left-layers.png

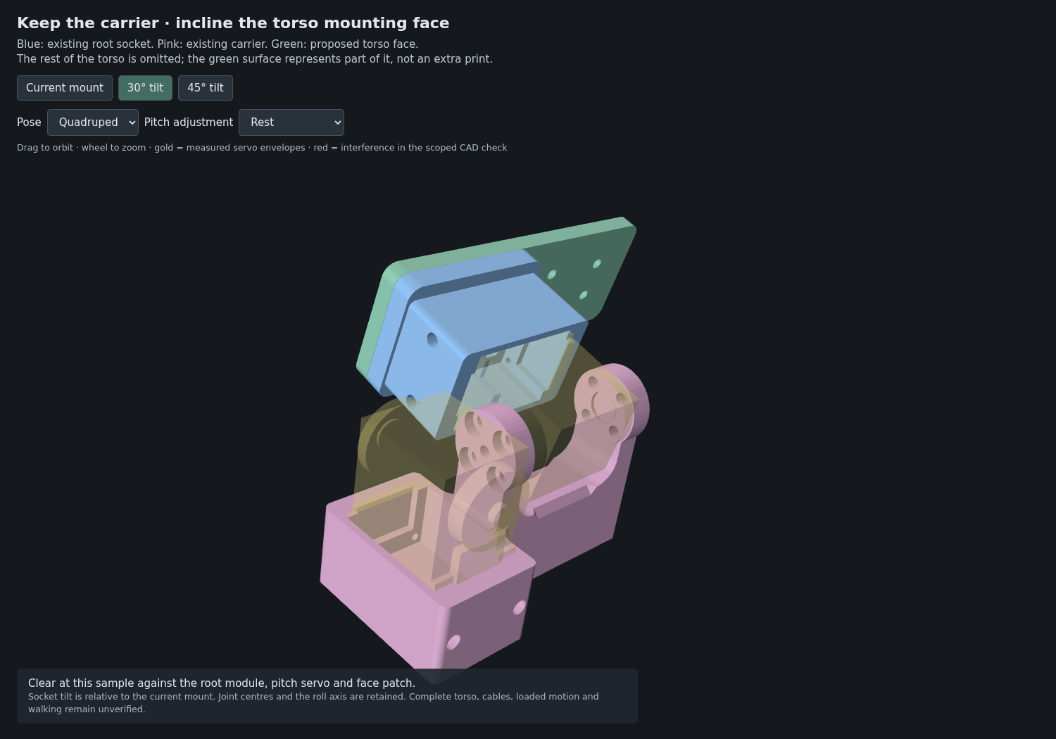
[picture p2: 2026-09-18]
docs/design/carrier-orientation/pitch-socket-30-rest.png

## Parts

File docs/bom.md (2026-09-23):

# Bill of Materials — Koala V1

Two halves: **bought** parts (below) and **printed** parts (generated from the
CAD, so it cannot drift from the geometry). Prices are UK, inc VAT, ~2026.
Full sourcing rationale and alternatives: [`sourcing.md`](sourcing.md).

**Status, 2026-09-21:** the generated tables describe the **walking first build**:
two footed rear shanks, four identical TPU pads and no fitted rear drive hardware.
They also list the replacement shanks and fastener changes for the wheeled
configuration (DEC-62). Bought drive parts remain allocated to the end goal.
Root socket v1 is physically proven,
with the recorded ear-hole support caveat; revised front parts, torso and thigh
remain unprinted. Deliveries and allocations are recorded below. The bought
neck set contains three small STS3032M servos plus one spare.
[Current assembly](cad-integrated-design.md) · [Physical evidence](test-log.md).

**DEC-43 (2026-09-10):** retain the bought rear 37D motor, wheel and hub pair
at the ankles. Front motors, wheels and extra drive channels are cancelled.
Integrated forearms now terminate in fixed rounded feet; the generated tables
now distinguish the wheeled configuration from the first walking build. Foot traction, head/neck, guards
and full power/electronics packaging remain open.

**DEC-51 (2026-09-11):** a second 37D pair and two more TB9051FTGs, ordered for the
cancelled four-wheel V1 (DEC-38), arrived and are **not koala-bot's**. This BOM stays at
two motors and one driver; the surplus is pooled in
[wk-robotics `common.md`](https://github.com/WayneKennedy/wk-robotics/blob/main/docs/common.md#drive-motors-drivers-and-mcus-in-hand).

## Bought — drive & balance base *(The Pi Hut #1614498, ordered 2026-09-01, delivered 2026-09-03; £159.50 goods + £3.80 shipping = £163.30)*

| Part | Qty | £ | Role |
|---|-----|---|---|
| Pololu Dual TB9051FTG motor driver | 1 | 30.70 | drive motors (DEC-16); in hand — the 2026-09-07 loan to wk-devastator is dissolved by DEC-51 |
| 37D 12V 122RPM 38 kg.cm geared motor + encoder | 2 | 55.80 | wheel-foot drive (DEC-31) |
| Pololu 80x10 mm wheel pair | 1 | 8.40 | Ø80 mm control constant (DEC-19) |
| Pololu 6 mm universal mounting hub (2-pack) | 1 | 12.50 | wheel to 6 mm D-shaft |
| Adafruit BNO085 9-DOF IMU | 1 | 27.00 | balance loop attitude |
| Teensy 4.0 + header kit | 1 | 25.10 | MCU / spinal cord (DEC-18) |

## Bought — servos *(AliExpress #3075773528793179, ordered 2026-09-01, delivered 2026-09-12; £254.31 paid, no shipping line)*

Line prices are as invoiced (AliExpress order and PayPal receipt, read 2026-09-17); the
earlier ~£302 and per-line figures were listing estimates. The seller is recorded here as
RCmall; the order emails name only AliExpress. No courier VAT or handling charge was found
in the mail.

| Part | Qty | £ | Role |
|---|-----|---|---|
| Feetech STS3215 12V 30 kg.cm 6-pack | 3 | 84.95 ea ×2, 103.15 ×1 | 12 limb joints (6 arm, 4 hip, 2 knee — DEC-31). Four of the first twelve went to SO-ARM101 on 2026-09-12 ([wk-soarm101 DEC-09](https://github.com/WayneKennedy/wk-soarm101/blob/main/docs/decisions.md)) and stay there permanently; the backfill 6-pack ordered 2026-09-14 **arrived 2026-09-22** (owner). **14 in hand: 12 for the limbs, 2 spare** — the supply half of OQ-16 is closed. The six new units' firmware is unread, expected 3.10 and read when their IDs are set (`sourcing.md`) |
| Feetech STS3032M 6V 4.5 kg.cm 4-pack | 1 | 78.38 | 3 neck (3-RPS) + 1 spare. Fixed single cable — chains board-to-board through the supplied 3-port connector boards and link cable, not servo-to-servo (`test-log.md` 2026-09-12) |
| STS3215 metal bracket set | 1 | 6.03 | dimensional reference (DEC-21) |

Of the STS3215s, the **lower body uses 6**: 2 hip-roll + 2 hip-pitch + 2 knee.

### Bought separately — test-fit servos *(Amazon 204-4694570-7173960, ordered 2026-09-02, delivered 2026-09-04)*

| Part | Qty | £ | Role |
|---|-----|---|---|
| Waveshare **ST3215 12V** bus servo | 2 | 31.90 ea (listing names neither Waveshare nor 12 V) | something to test-fit printed parts against, ahead of the RCmall order |

Bought to have real cases on the bench. **What was in the box is a BOM fact:**
M3 servo horn screws **and M2×5 self-tapping screws** for the case fixing
holes — so the retention screw is **M2**, not the M2.5 previously assumed
(`SELFTAP_DIA`, and see [`test-log.md`](test-log.md) 2026-09-07). **The RCmall
Feetech 6-packs ship the same accessories (owner report 2026-09-12): two metal
horns per servo, M3×6 pan-head horn screws, and M2 self-tappers — read as M2×6,
against Waveshare's M2×5, unmeasured.** No bus adapter. [SPEC 11]
says the bare servo ships with *No Accessories*, which evidently describes the
part, not a retail box. Waveshare's ST3215 is a rebadge of the same Feetech
servo; the maintainer confirms fit against the SO-101 printed interfaces in
PLA+ and PETG (DEC-33), without claiming new caliper readings.

## Bought — fasteners & consumables *(NOT yet ordered, ~£15–25 + filament)*

The **generated fastening schedule below** replaces the discarded draft's
counts. It covers all twelve limb joints: 24 metal horns/idlers, 96 horn-square screws,
twelve drive-centre fixings, 48 M2×5 ear screws and 48 narrow OD6 × 0.5 mm
Back-horn washers. Both rear motor-face mounts are included.
Check kit contents and stock before buying; the rig must establish actual
engagement, head clearance and horn span. Wheel/hub fixings depend on the
supplied kits and remain outside this count.

PETG filament remains a consumable; a 1 kg spool is the sourcing unit, not a
measured requirement. Inserts and an insert tip are needed only for the
retained seam/insert coupons; the torso's structural seams use
through-bolts and metal nuts. Assembly order and candidate stacks are in
[`cad-integrated-design.md`](cad-integrated-design.md).

Bench power for bring-up (12 V source) is still outstanding — a 3S LiPo is the
DEC-20 answer, not a bench PSU.

## Print settings

What the **design** requires is short, and it is all koala-bot asserts:

- **PETG** (DEC-09), printed in each part's **declared orientation**, with
  integrated structures and accessible local supports allowed (DEC-39). Inspect
  sliced layers first, especially the opposite fork, saddle, motor ring and screw-head pockets.
- A **brim** on tall, small-footprint parts — flagged per part in the table.

Parts are **not** printed solid; strength comes from perimeters and orientation,
not from filling the part.

### Slice evidence

Current revised parts have [local organic-support review slices](design/front-redesign/README.md#printability-and-service),
using the shared printer profile with Koala's `manufacturing-petg-tree.ini`
overrides: four perimeters, 30% infill, 0.2 mm layers, bed-only organic support
and a 4 mm brim. The record identifies the slicer, exact STL/G-code hashes and
profile hashes. Earlier [manufacturing records](design/manufacturing/README.md)
apply only to matching STL hashes. These estimates and inspected layers do not
establish support removal, strength or creep resistance; physical acceptance
remains open. Any slicer may be used if it meets the design requirements.

## Printed parts

These tables describe the **current integrated chassis**. Every part fits
≤200 × 200 mm in its declared orientation. Surface metrics do not certify
support-free printing or strength. Regenerate with
`cd hardware && uv run python -m koala_hardware.export`.

<!-- BEGIN GENERATED: printed parts -->

*Generated by `koala_hardware.export` - do not hand-edit. Walking first build (DEC-62); coupons and alternative shanks are excluded from the total.*

Figures with a matching STL hash are **slicer estimates** using the recorded PETG/TPU review settings (`docs/design/manufacturing/slices.json` and `docs/design/front-redesign/slices.json`, plus `docs/design/walking/slices.json`); changed or unsliced parts fall back to a labelled solid-geometry upper bound. All structural parts printed solid would be 1013 g.

| Part | Ver | Qty | Printable | Material | Size (mm) | Filament | Print time | Print notes |
|---|-----|-----|---|---|---|---|---|---|
| `e_tray` | v1 | 1 | assumed | PETG | 96 x 88 x 9 | ~43 g (solid max) | - | clean |
| `foot_shank_left` | v1 | 1 | unknown | PETG | 49 x 103 x 21 | 30 g | 2h 59m 44s | 1041 mm2 flagged overhang; inspect slice |
| `foot_shank_right` | v1 | 1 | unknown | PETG | 49 x 103 x 21 | 30 g | 2h 59m 49s | 1041 mm2 flagged overhang; inspect slice |
| `forearm_left` | v2 | 1 | unknown | PETG | 49 x 113 x 21 | 34 g | 3h 18m 26s | 1041 mm2 flagged overhang; inspect slice |
| `forearm_right` | v2 | 1 | unknown | PETG | 49 x 113 x 21 | 34 g | 3h 18m 34s | 1041 mm2 flagged overhang; inspect slice |
| `front_contact_pad` | v1 | 4 | assumed | TPU | 32 x 32 x 20 | 30 g | 1h 11m 17s | 4 mm2 flagged overhang; inspect slice |
| `hip_carrier_left` | v1 | 1 | assumed | PETG | 45 x 78 x 51 | ~46 g (solid max) | - | 282 mm2 flagged overhang; inspect slice |
| `hip_carrier_right` | v1 | 1 | assumed | PETG | 45 x 78 x 51 | ~46 g (solid max) | - | 282 mm2 flagged overhang; inspect slice |
| `root_socket_left` | v1 | 2 | proven | PETG | 47 x 37 x 28 | ~60 g (solid max) | - | 70 mm2 flagged overhang; inspect slice |
| `root_socket_right` | v1 | 2 | proven | PETG | 47 x 37 x 28 | ~60 g (solid max) | - | 70 mm2 flagged overhang; inspect slice |
| `shoulder_carrier_left` | v3 | 1 | unknown | PETG | 49 x 73 x 51 | 40 g | 4h 27m 11s | 562 mm2 flagged overhang; inspect slice |
| `shoulder_carrier_right` | v3 | 1 | unknown | PETG | 49 x 73 x 51 | 39 g | 4h 27m 20s | 562 mm2 flagged overhang; inspect slice |
| `shoulder_mount_left` | v1 | 1 | unknown | PETG | 44 x 47 x 32 | 16 g | 1h 42m 4s | 70 mm2 flagged overhang; inspect slice |
| `shoulder_mount_right` | v1 | 1 | unknown | PETG | 44 x 47 x 32 | 16 g | 1h 42m 7s | 70 mm2 flagged overhang; inspect slice |
| `thigh_left` | v3 | 1 | unknown | PETG | 45 x 110 x 73 | 50 g | 5h 12m 18s | 1924 mm2 flagged overhang; inspect slice |
| `thigh_right` | v3 | 1 | unknown | PETG | 45 x 110 x 73 | 50 g | 5h 14m 57s | 1924 mm2 flagged overhang; inspect slice |
| `torso_frame` | v5 | 1 | unknown | PETG | 164 x 94 x 82 | 165 g | 15h 48m 59s | 4569 mm2 flagged overhang; inspect slice |
| `tray_spacer` | v1 | 4 | assumed | PETG | 7 x 7 x 4 | 1 g | 2m 35s | small contact area; brim / grouped placement |
| `upper_arm_left` | v2 | 1 | unknown | PETG | 62 x 29 x 49 | 32 g | 3h 18m 50s | 1107 mm2 flagged overhang; inspect slice |
| `upper_arm_right` | v2 | 1 | unknown | PETG | 62 x 29 x 49 | 32 g | 3h 18m 19s | 1107 mm2 flagged overhang; inspect slice |
| `coupon_ladder` | v1 | 1 | assumed | PETG | 150 x 60 x 6 | 42 g | 4h 28m 46s | clean |
| `coupon_motor_bore` | v1 | 1 | assumed | PETG | 135 x 50 x 6 | 20 g | 1h 53m 22s | clean |
| `coupon_motor_ring` | v1 | 1 | assumed | PETG | 47 x 47 x 5 | 8 g | 53m 24s | clean |
| `coupon_seam` | v1 | 1 | assumed | PETG | 60 x 75 x 13 | 16 g | 1h 49m 20s | 38 mm2 flagged overhang; inspect slice |
| `coupon_socket_fork` | v1 | 1 | assumed | PETG | 42 x 21 x 49 | ~21 g (solid max) | - | 568 mm2 flagged overhang; inspect slice |
| `coupon_socket_saddle` | v1 | 1 | assumed | PETG | 45 x 29 x 22 | 16 g | 1h 36m 50s | 70 mm2 flagged overhang; inspect slice |
| **Structural total** | | **28** | | | | **~1013 g (solid max)** | **-** | |

**Wheeled alternative (exchange at both knees).** Replace the two `foot_shank` prints and their two rear TPU pads with the following prints. Keep the two front pads and the shared upper chassis. Fit the retained motor/hub/wheel pairs. Quantities below are alternatives, excluded from the walking total.

| Alternative print | Ver | Qty | Printable | Material | Size (mm) |
|---|---|---:|---|---|---|
| `shank_right` | v2 | 1 | assumed | PETG | 123 x 46 x 49 |
| `shank_left` | v2 | 1 | assumed | PETG | 123 x 46 x 49 |

Wheeled configuration: **26 physical prints**; walking configuration: **28**.

**Walking chassis fastening schedule, derived from the same builders.** Candidate lengths require rig checks; excludes coupon hardware, head/neck mechanisms and supplier-specific wheel/hub fixings.

| Fastener / interface hardware | Qty |
|---|---:|
| M2x5 self-tapper into servo ear | 48 |
| M3 drive-horn centre fixing (supplied kit) | 12 |
| M3 narrow washer OD6 x 0.5, idler horn screws | 48 |
| M3 nut | 12 |
| M3 nut, captive in shoulder cassette | 8 |
| M3 nut, captive under the servo | 16 |
| M3 plain washer | 16 |
| M3x16 Uno driver-board bolt (stack to verify) | 4 |
| M3x16 root screw, from the torso side | 16 |
| M3x20 TPU-pad screw | 4 |
| M3x20 shoulder cassette-to-frame screw | 8 |
| M3x25 tray through-bolt | 4 |
| M3x6 supplied horn-square pan screw (bottoming to verify) | 96 |
| Metal 9.9-square horn/idler | 24 |

**Fastener changes for the wheeled configuration:**

| Fastener | Walking | Wheeled |
|---|---:|---:|
| M3 nut | 12 | 10 |
| M3 plain washer | 16 | 14 |
| M3x20 TPU-pad screw | 4 | 2 |
| M3x8 motor-face screw (depth to verify) | 0 | 12 |

<!-- END GENERATED -->

Coupons are the **test-fit pieces printed first**: each one verifies a
`[VERIFY]` constant in `hardware/src/koala_hardware/params.py` against the real
hardware. Adjust the constant, regenerate, reprint until it fits — then commit
to the structural parts.

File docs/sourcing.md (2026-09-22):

# Sourcing (UK-focused)

Prices ~2026, approximate. UK import: **VAT 20%** applies; the **£135 threshold** (goods
value, excl. shipping) decides *how* - under it the seller charges VAT at checkout (no
fee); over it the courier collects VAT + a ~£8-12 handling fee. Keeping a China order
under ~£135 of goods avoids the fee.

## Confirmed order - drive/balance base (The Pi Hut #1614498, £163.30 inc VAT) [PURCHASED 2026-09-01, DELIVERED 2026-09-03]

The self-balancing base subsystem (limb/head servos are a separate import order):

| Part | Qty | £ inc VAT |
|---|-----|---|
| Pololu Dual TB9051FTG motor driver (DEC-16) — in hand; the 2026-09-07 loan to wk-devastator is dissolved by DEC-51 | 1 | 30.70 |
| Pi Hut 37D 12V 122RPM 38 kg.cm geared motor + encoder | 2 | 55.80 |
| Pololu Wheel 80x10 mm pair (Ø80 mm = control constant, DEC-19) | 1 | 8.40 |
| Pololu 6 mm universal mounting hub (2-pack) | 1 | 12.50 |
| Adafruit BNO085 9-DOF IMU (fusion, I2C/Qwiic) | 1 | 27.00 |
| Teensy 4.0 (DEC-18) + header kit | 1 | 25.10 |
| **Goods** | | **159.50** |
| Shipping | | 3.80 |
| **Order total** (invoice, incl. £27.22 VAT) | | **163.30** |

Not in this order: a **3S LiPo** for bring-up — **DEC-20**, *not* a bench PSU, which this
line previously offered as an equal option and should not have (the exception is servo ID
assignment and current measurement, where a current-limited supply is the safer tool; see
[wk-robotics `common.md`](https://github.com/WayneKennedy/wk-robotics/blob/main/docs/common.md#power-integrity)).
Also outstanding: optional STEMMA QT cable for the BNO085.

## Confirmed order - servos (AliExpress #3075773528793179, £254.31 paid) [PURCHASED 2026-09-01, ARRIVED 2026-09-12]

Prices as invoiced (order confirmation and PayPal receipt, read 2026-09-17), replacing the
listing estimates (~£302) recorded at purchase. No shipping line. The seller is recorded as
RCmall; the emails name only AliExpress. Goods exceeded the £135 threshold above, yet no
courier VAT or handling charge was found in the mail.

| Part | Qty | £ inc VAT | Role |
|---|-----|---|---|
| Feetech STS3215 12V 30 kg 6-pack (listed with FE-URT-1 — **none shipped**, 2026-09-12) | 2 | 84.95 ea | 12 limb joints (DEC-31). **Four reallocated to SO-ARM101 2026-09-12, permanently**; eight remain. **Backfill 6-pack ordered 2026-09-14 and delivered 2026-09-22** (AliExpress #3076088966873179, £103.15 paid; shipped 2026-09-15, cleared UK customs and arrived 2026-09-22, owner) — 14 STS3215 now in hand; see `bom.md` |
| Feetech STS3032M 6V 4.5 kg metal-case 4-pack (DEC-22) | 1 | 78.38 | 3 neck (3-RPS) + 1 spare |
| STS3215 metal bracket set | 1 | 6.03 | dimensional reference - **brackets are printed** (DEC-21). Arrived 2026-09-12; the servos themselves ship without brackets |

Neck servos are 6V -> a separate 6V bus segment from the 12V limb bus (same STS protocol).

**Arrived 2026-09-12** — 12 × STS3215 and 4 × STS3032M, counts confirmed by the owner.
**Backfill pack arrived 2026-09-22** — 6 × STS3215 (owner). Box contents not yet listed.
Firmware unread, and **expected to be 3.10**: the only 3.9 units the family has found are the
two Waveshare/Amazon ones, while every Feetech unit read so far shipped 3.10. It is read when
their IDs are assigned, not as a separate step (owner, 2026-09-22); a bus must be all-3.10
([wk-robotics `common.md`](https://github.com/WayneKennedy/wk-robotics/blob/main/docs/common.md#holdings-and-electrical-operation)).
**Each STS3215 ships with a drive horn, an idler horn, M3×6 pan-head horn screws and
M2×6 self-tapping case screws — and no serial-bus adapter.** The listing's FE-URT-1 was
not in either 6-pack; the family's adapters cover it (Waveshare Bus Servo Adapter (A),
FE-URT-2). **Each STS3032M ships with a fixed single cable — no pass-through port — plus
one aluminium and three plastic horns, mounting screws, a small 3-port connector board and
a separate cable to daisy-chain the boards.** Full contents tables in [`test-log.md`](test-log.md)
2026-09-12.

## Test-fit pair (Amazon 204-4694570-7173960, ordered 2026-09-02, delivered 2026-09-04)

Two **Waveshare ST3215 12V** servos, bought outside the plan to have real cases on
the bench while printed parts are still being fitted. Amazon is the instant-but-dear
route already noted below (~£28 each at the time of that research; this purchase was
£31.90 each, £63.80, per the order email). The listing names neither Waveshare nor 12 V. Its value was **what came in the box** - M2x5 self-tapping
case screws and M3 horn screws, which is a BOM fact, recorded in
[`bom.md`](bom.md) and [`test-log.md`](test-log.md). Whether the RCmall Feetech
6-packs ship the same accessories is unverified.

**Reallocated 2026-09-09:** both units are now SO-ARM101 follower servos (`shoulder_pan`
ID 1, `shoulder_lift` ID 2) — see [wk-soarm101 `docs/servos.md`](https://github.com/WayneKennedy/wk-soarm101/blob/main/docs/servos.md). The koala-bot bench had
no STS3215 from then until the 6-packs arrived on 2026-09-12.

## Four-wheel hardware (DEC-38) — arrived 2026-09-11, surplus

Two more 37D 12 V 122 rpm 38 kg.cm motors + encoders (£55.80) and **two** more Pololu
Dual TB9051FTGs (£61.40), ordered for DEC-38's four driven wheels on The Pi Hut #1619429,
2026-09-10, delivered 2026-09-11. The same order held a Teensy 4.1 NE (£28.50), pooled in
wk-robotics `common.md`; order total £149.50 inc £3.80 shipping. DEC-43 cancelled the
front drives on 2026-09-10, the day they were ordered. **Not koala-bot's**
— allocated by DEC-51: one driver is wk-devastator's own (ending its loan), the other
driver and both motors are pooled in [wk-robotics `common.md`](https://github.com/WayneKennedy/wk-robotics/blob/main/docs/common.md#drive-motors-drivers-and-mcus-in-hand).

## Part notes & alternatives (pre-purchase research, kept for reference)

- **STS3215 (limbs):** chosen route was RCmall/AliExpress (SO-ARM-style listing,
  ~£17.3 landed). Alternatives: Seeed Studio ~£25 (guaranteed genuine), Amazon UK ~£28
  (instant). One voltage (**12 V**) across all limb servos; the **FE-URT-1** USB
  serial-bus adapter (sets servo IDs) is bundled in many kits.
  What we bought maps exactly onto the **SO-101 "Pro" follower** spec - 12 V, 1:345 gear
  ratio, 30 kg.cm - the official upgraded variant, not an off-standard part, which is what
  makes DEC-21 compatibility concrete rather than assumed. (The SO-101 *leader* arm is 7.4 V
  with three mixed gear ratios; koala-bot has no leader, so all 12 limb servos are a single
  uniform part number and share one spares pool.)
- **Drive motors:** Pi Hut 37D-class 12V 122RPM 38 kg.cm w/encoder (chosen).
  N20+encoder is too weak for the main drive (fine for small joints).
- **Motor driver:** Pololu Dual TB9051FTG (chosen; DEC-16) - 4.5-28 V, current sense
  (~500 mV/A), over-current/thermal protection, low-loss; Arduino *shield* form factor,
  wired as a breakout to the Teensy; watch thermals if heavy. Higher-current
  alternatives: Cytron MDD3A, Pololu G2. Avoid **L298N** (lossy BJT, ~2 V drop).
- **MCU:** Teensy 4.0 (chosen; DEC-18; Pi Hut / Pimoroni / Cool Components).
  RP2040 / ESP32 (~£4-8) are cheaper micro-ROS-capable variants; ESP32 adds wireless.
- **Power:** 3S LiPo (~11.1 V nominal) -> motors + 12 V servos direct; **5 V buck**
  (generous) for the Pi 5.
- **Fasteners (DEC-23/24, not yet ordered):** M3 screws (8/12/16/50 mm — the 50s pass
  through the hip brackets' servo tabs), M3 brass heat-set inserts, M3 standoffs (10 mm,
  pelvis-to-tray), **M2 self-tapping screws** (servo case retention — the horn drive
  square is M3, not M2.5; see [`test-log.md`](test-log.md) 2026-09-02 and 2026-09-07),
  insert tip for a soldering iron — ~£12-18. Counts and lengths live in
  [`bom.md`](bom.md), which derives them from the CAD.

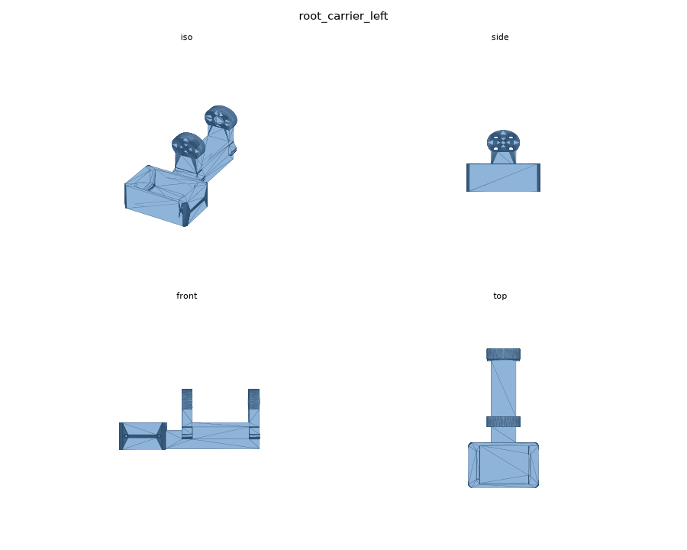
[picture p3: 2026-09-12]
docs/design/parts/root_carrier_left.png

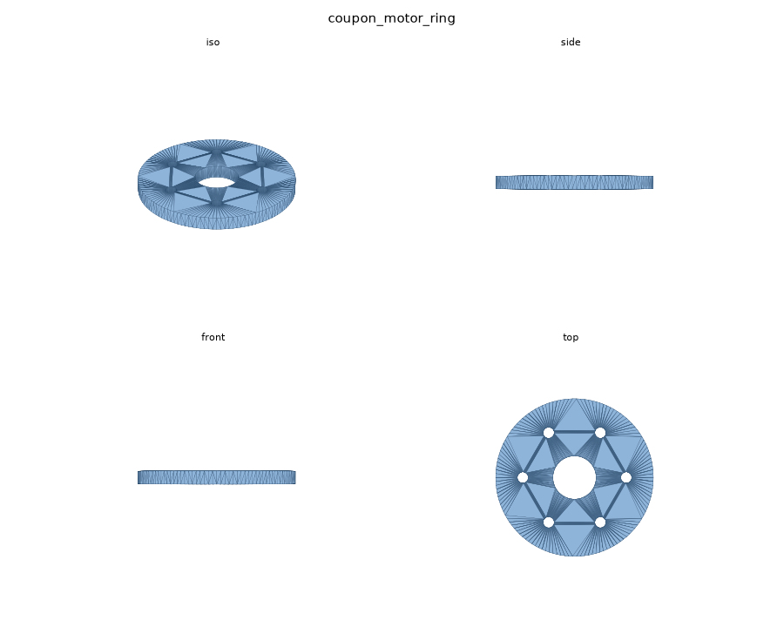
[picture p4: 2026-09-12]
docs/design/parts/coupon_motor_ring.png

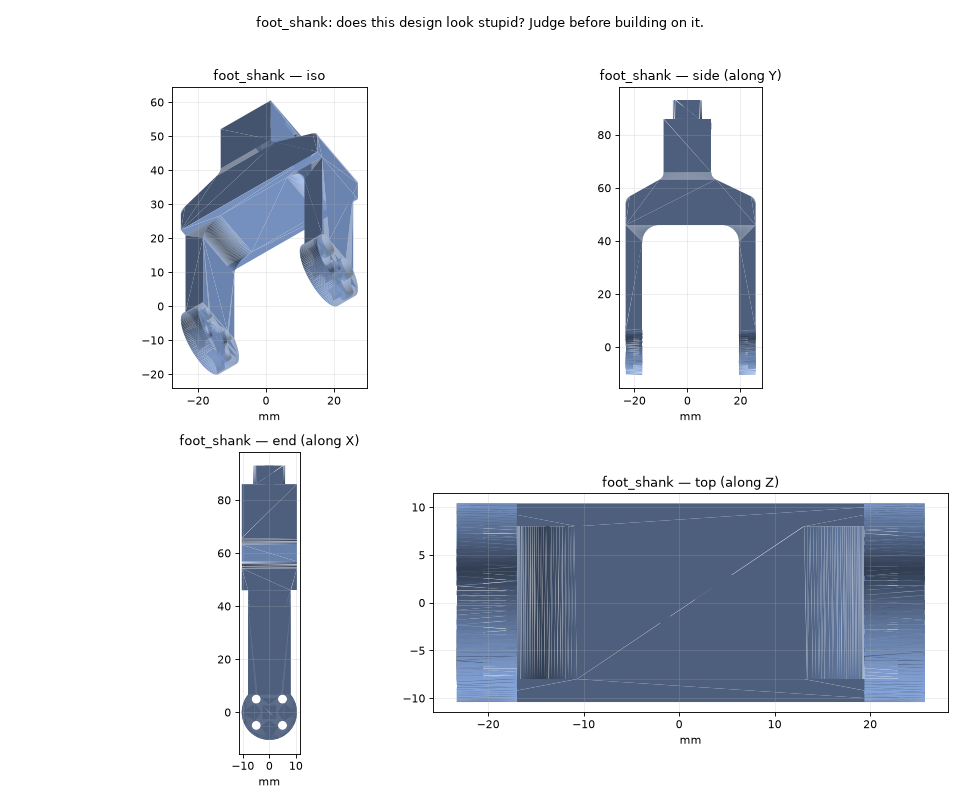
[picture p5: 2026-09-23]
docs/design/parts/foot_shank-views.png

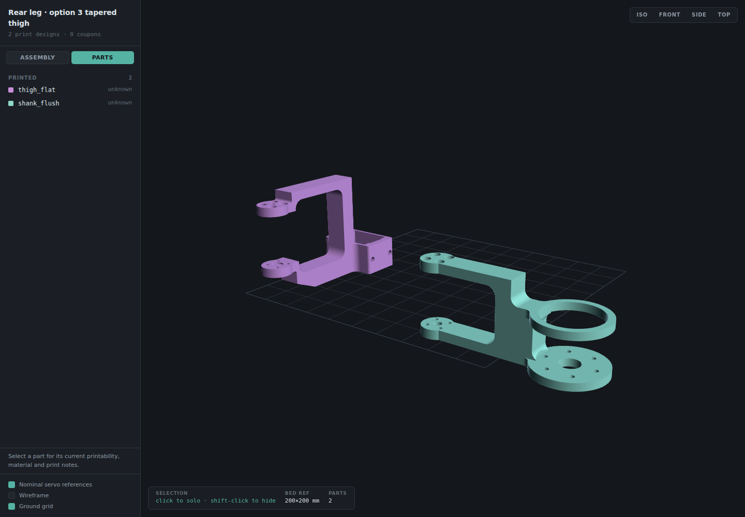
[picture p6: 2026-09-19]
docs/design/rear-leg/thigh-flat/viewer-parts.png

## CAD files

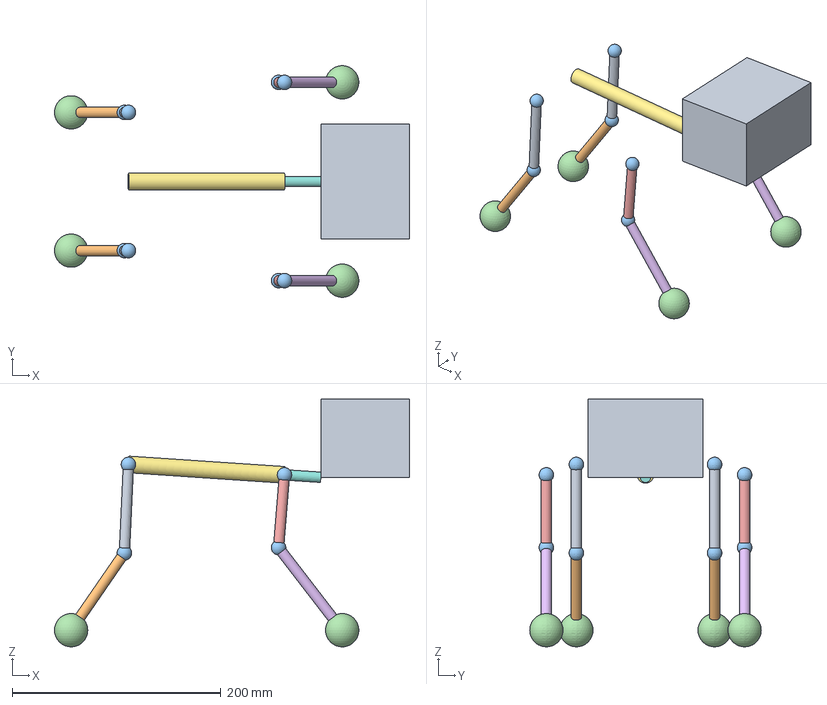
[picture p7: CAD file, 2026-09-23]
docs/design/body-walking.step
340.5 x 222.1 x 237.7 mm
rear_upper_-1
rear_lower_-1
rear_axis_0_-1
rear_axis_1_-1
rear_axis_2_-1
rear_foot_-1
front_upper_-1
front_lower_-1
front_axis_0_-1
front_axis_1_-1
front_axis_2_-1
front_foot_-1
rear_upper_1
rear_lower_1
rear_axis_0_1
rear_axis_1_1
rear_axis_2_1
rear_foot_1
front_upper_1
front_lower_1
front_axis_0_1
front_axis_1_1
front_axis_2_1
front_foot_1
torso_axis
neck_axis
head_envelope

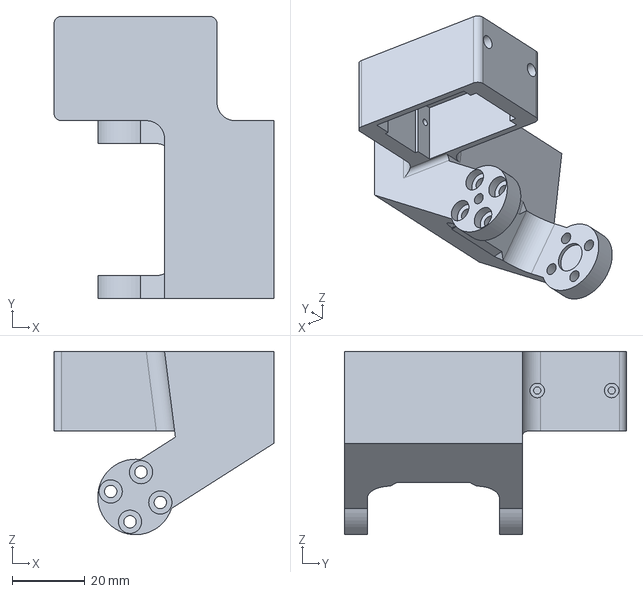
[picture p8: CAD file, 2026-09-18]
docs/design/carrier-orientation/angled-fork.step
60.6 x 77.7 x 50.5 mm

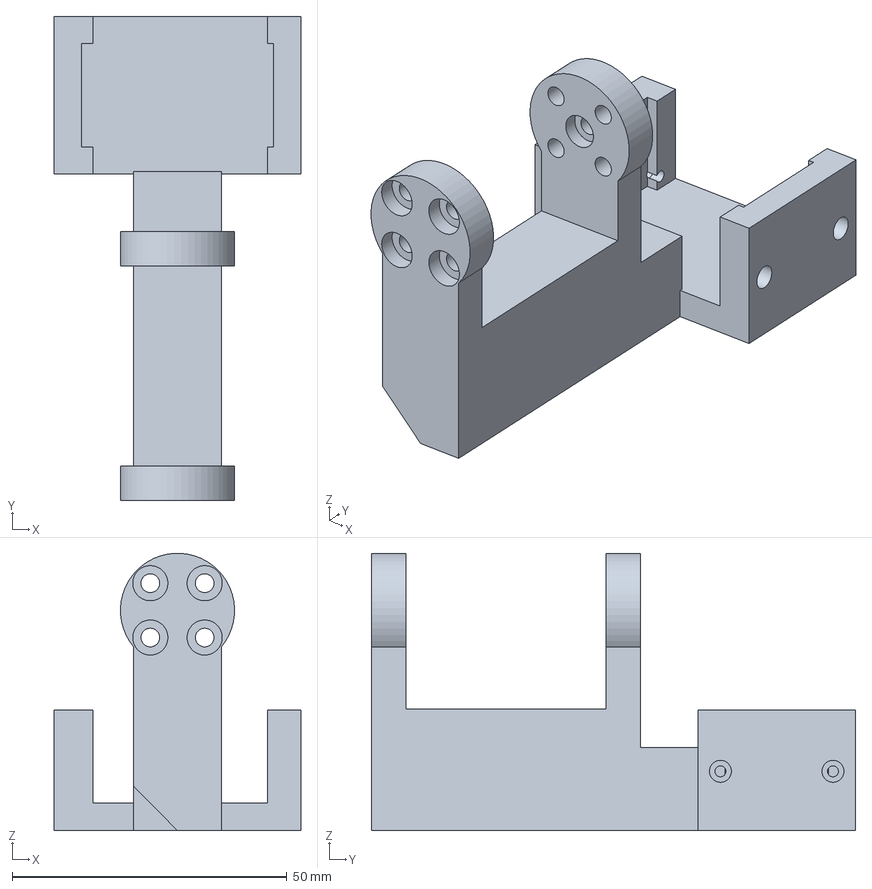
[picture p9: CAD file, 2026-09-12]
docs/design/front-carrier/flat-back-candidate.step
44.9 x 88.1 x 50.5 mm

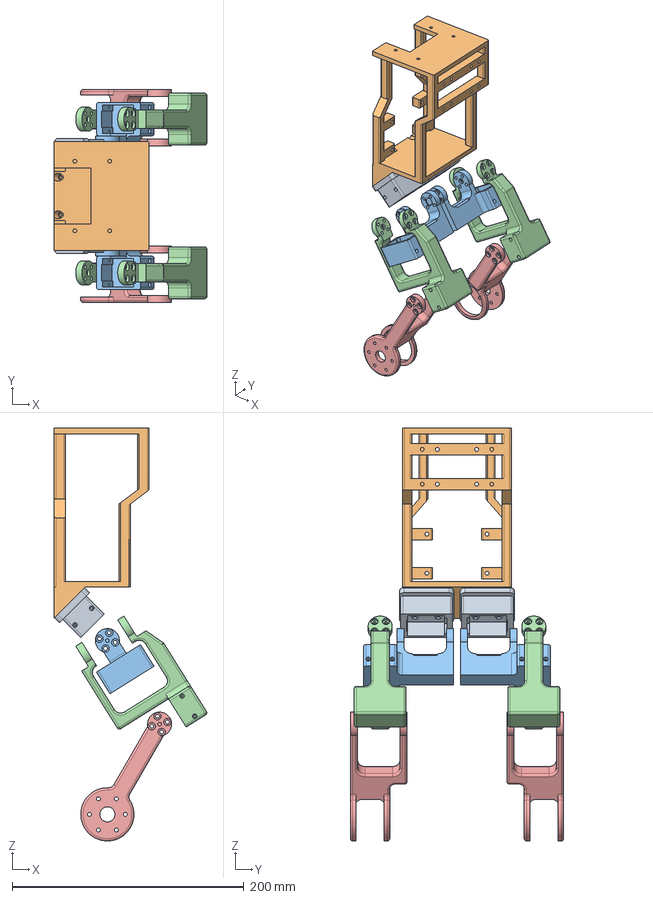
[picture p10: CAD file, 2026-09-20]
docs/design/rear-leg/rear-leg-upright.step
131.9 x 184.0 x 356.5 mm
pelvis_socket_right
pelvis_socket_left
torso_frame
rear_carrier_right
rear_thigh_right
rear_shank_right
rear_carrier_left
rear_thigh_left
rear_shank_left

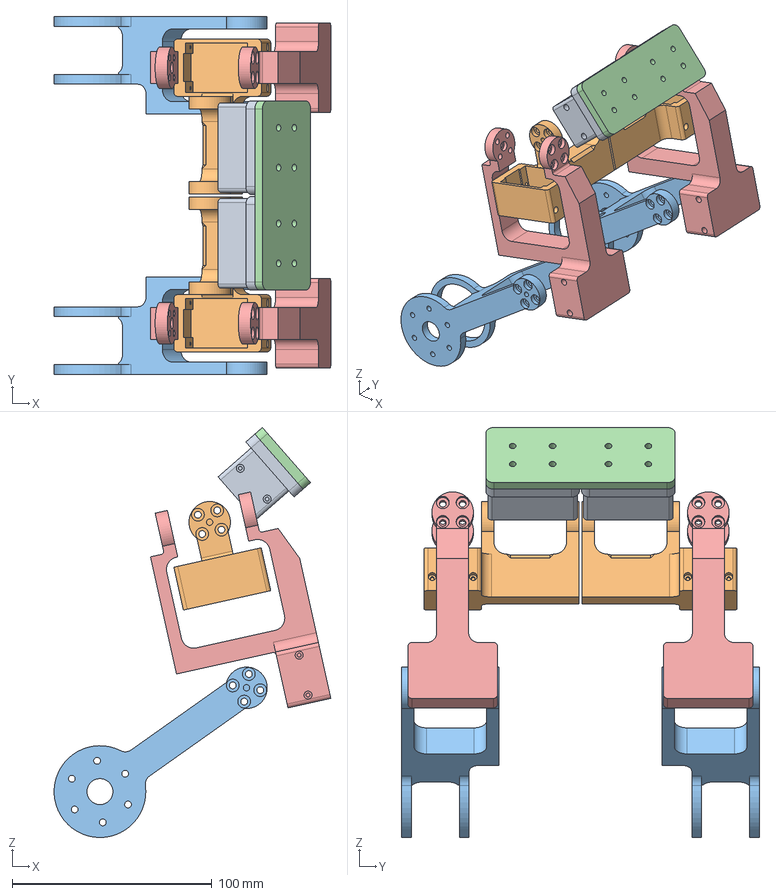
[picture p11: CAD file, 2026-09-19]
docs/design/rear-leg/thigh-flat/rear-leg-quadruped.step
138.7 x 179.5 x 205.5 mm
pelvis_socket_right
pelvis_socket_left
rear_carrier_right
rear_shank_right
rear_carrier_left
rear_shank_left
proposed_torso_face
rear_thigh_right
rear_thigh_left

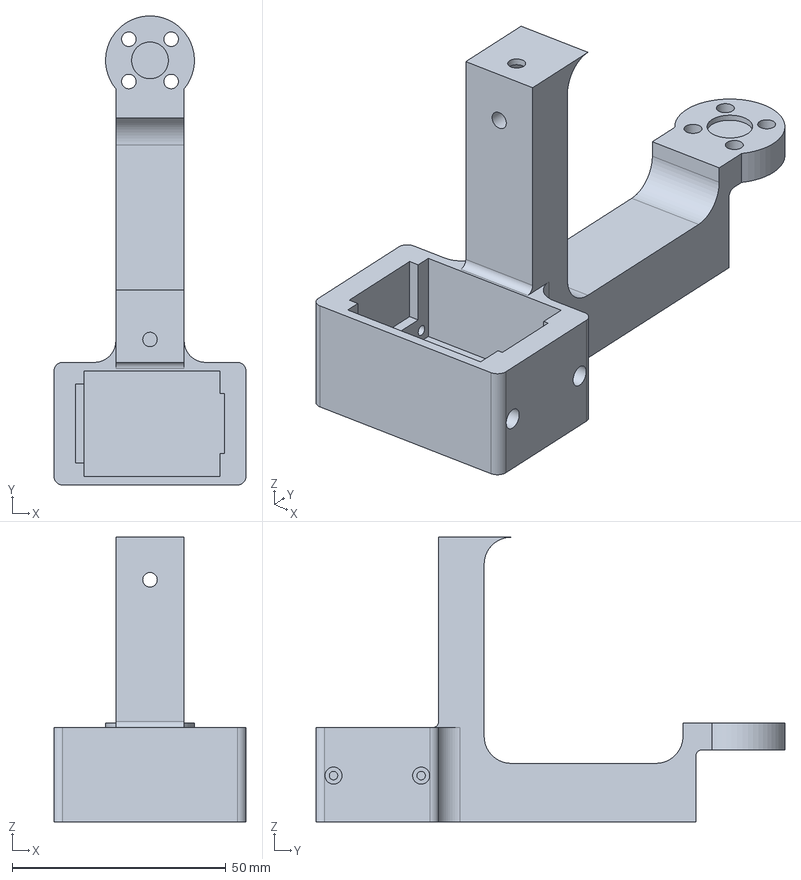
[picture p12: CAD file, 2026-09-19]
docs/design/rear-leg/thigh-options/thigh_body-left.step
44.9 x 109.7 x 66.6 mm

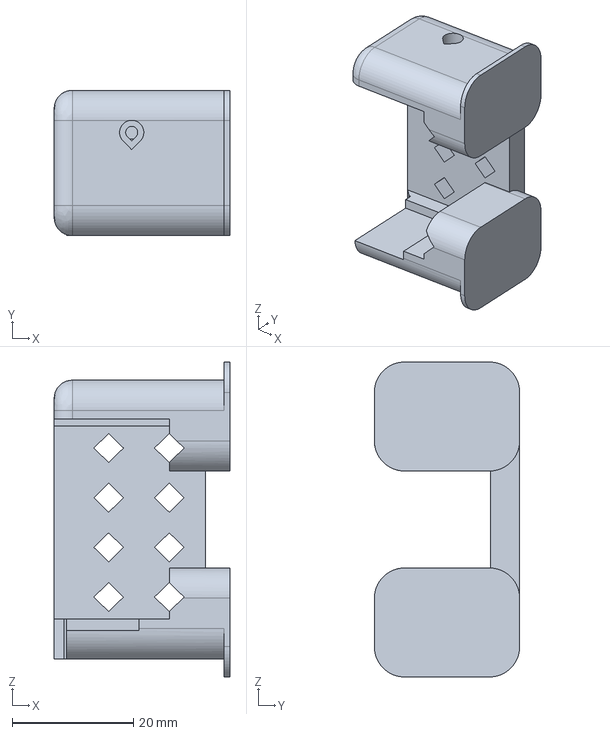
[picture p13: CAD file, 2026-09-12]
docs/design/so101/under_socket_source.step
29.0 x 24.0 x 52.0 mm

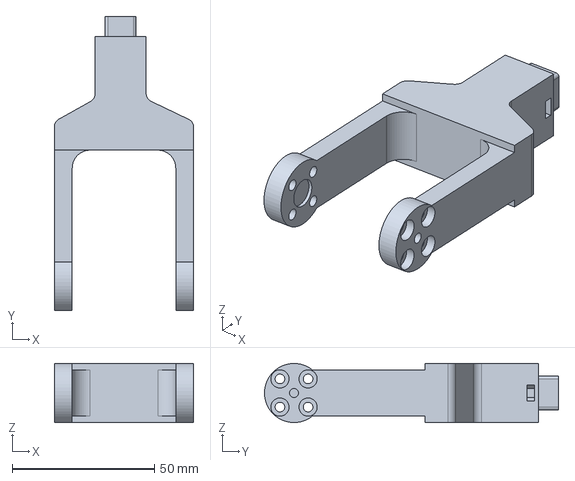
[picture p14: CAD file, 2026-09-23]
docs/design/walking/foot_shank_left-v1.step
49.0 x 103.4 x 20.8 mm

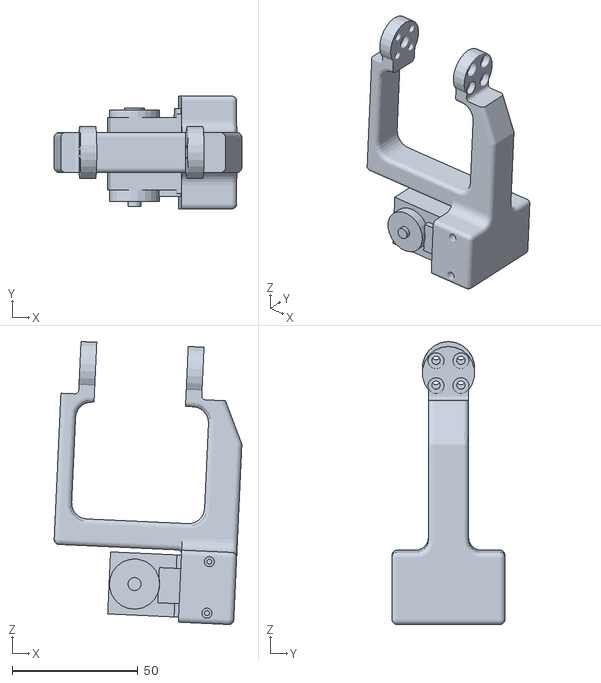
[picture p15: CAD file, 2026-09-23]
hardware/sim/meshes/rear_left_upper.stl
74.7 x 44.9 x 112.6

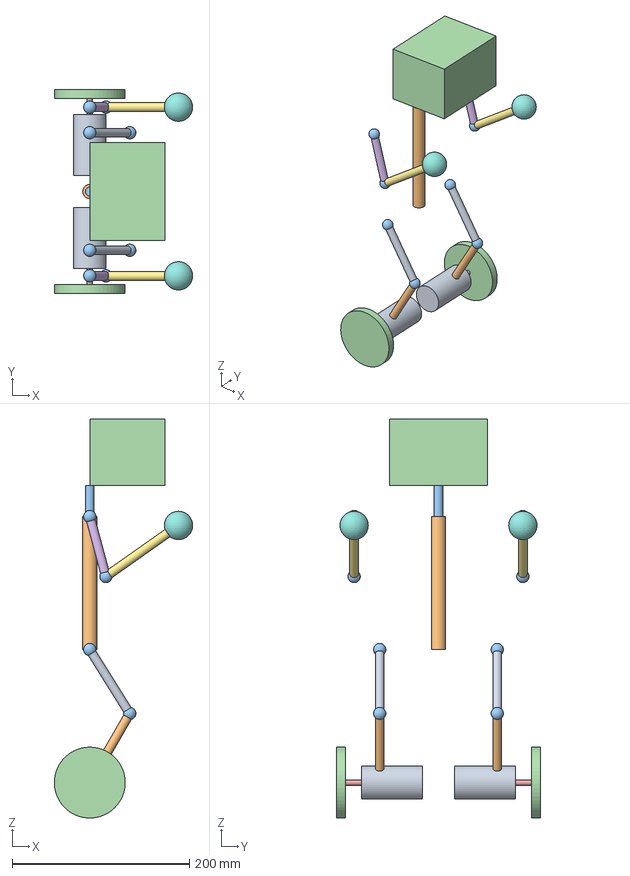
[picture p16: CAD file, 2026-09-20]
docs/design/body-upright.step
156.0 x 230.0 x 449.9 mm
rear_upper_-1
rear_lower_-1
rear_axis_0_-1
rear_axis_1_-1
rear_axis_2_-1
rear_wheel_-1
rear_axle_-1
front_upper_-1
front_lower_-1
front_axis_0_-1
front_axis_1_-1
front_axis_2_-1
front_foot_-1
rear_motor_-1
rear_upper_1
rear_lower_1
rear_axis_0_1
rear_axis_1_1
rear_axis_2_1
rear_wheel_1
rear_axle_1
front_upper_1
front_lower_1
front_axis_0_1
front_axis_1_1
front_axis_2_1
front_foot_1
rear_motor_1
torso_axis
neck_axis
head_envelope

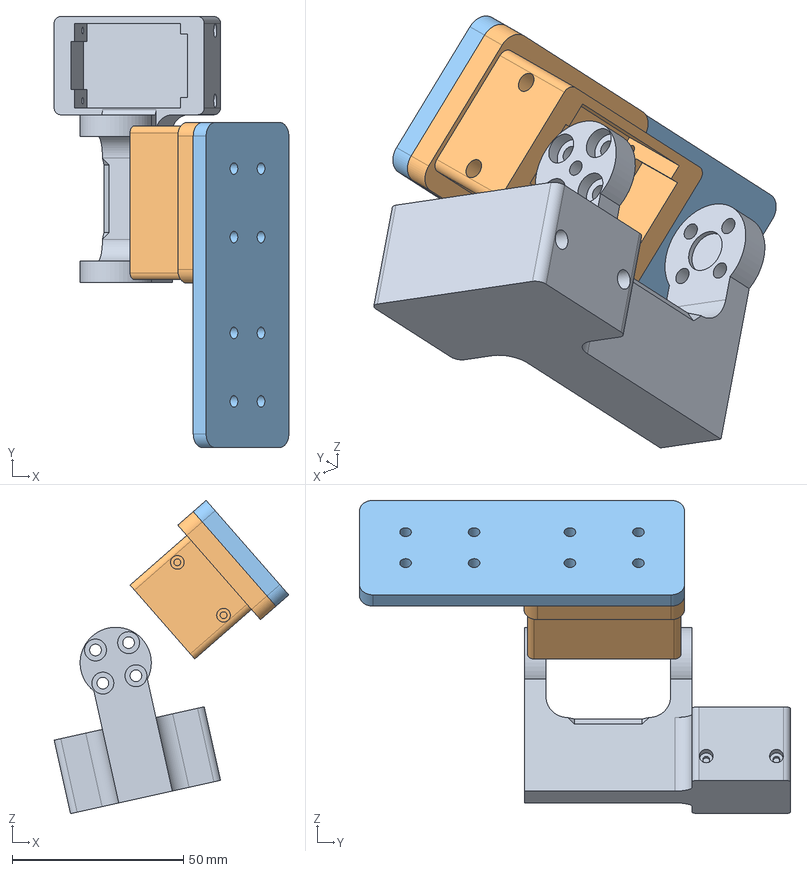
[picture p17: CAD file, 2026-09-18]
docs/design/carrier-orientation/pitch-socket-45.step
68.5 x 125.9 x 91.5 mm
retained_carrier
retained_root_socket
proposed_torso_face_patch

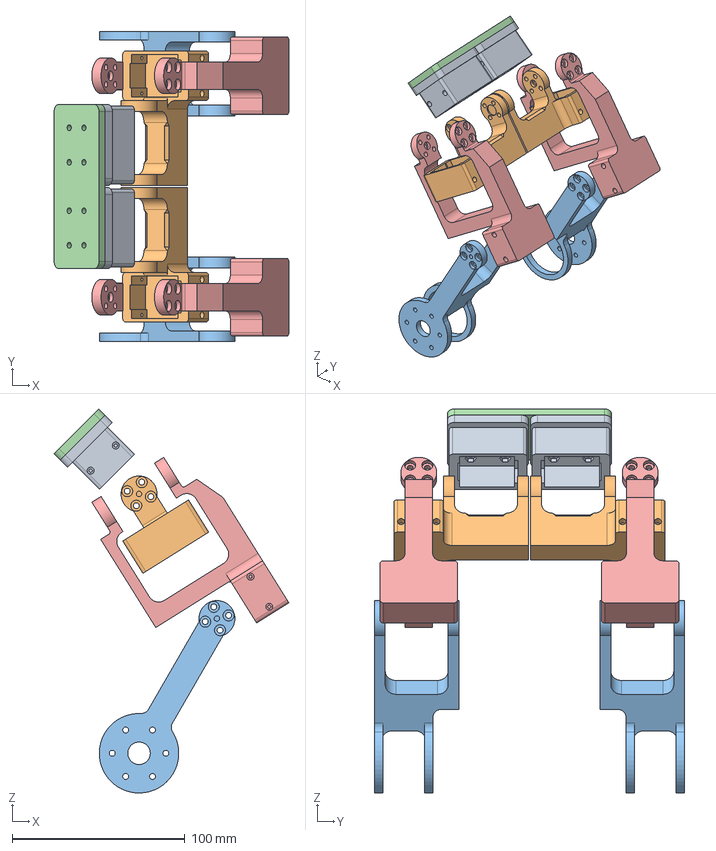
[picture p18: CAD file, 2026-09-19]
docs/design/rear-leg/thigh-flat/rear-leg-upright.step
135.8 x 179.5 x 222.1 mm
pelvis_socket_right
pelvis_socket_left
rear_carrier_right
rear_shank_right
rear_carrier_left
rear_shank_left
proposed_torso_face
rear_thigh_right
rear_thigh_left

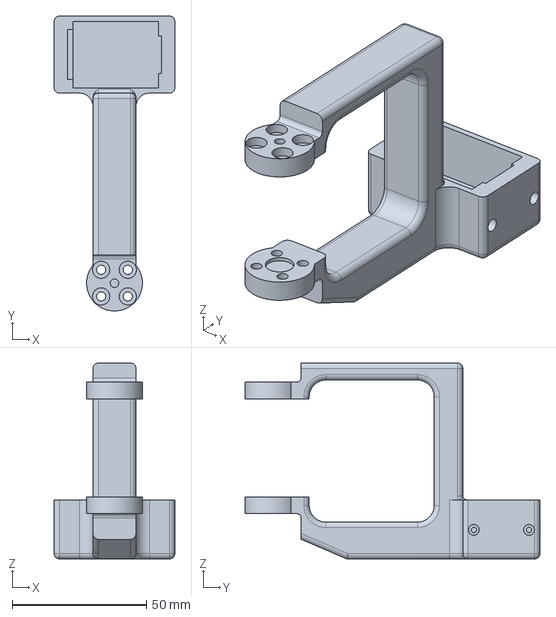
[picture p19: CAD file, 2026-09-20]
docs/design/rear-leg/thigh-right.step
44.9 x 109.7 x 72.9 mm

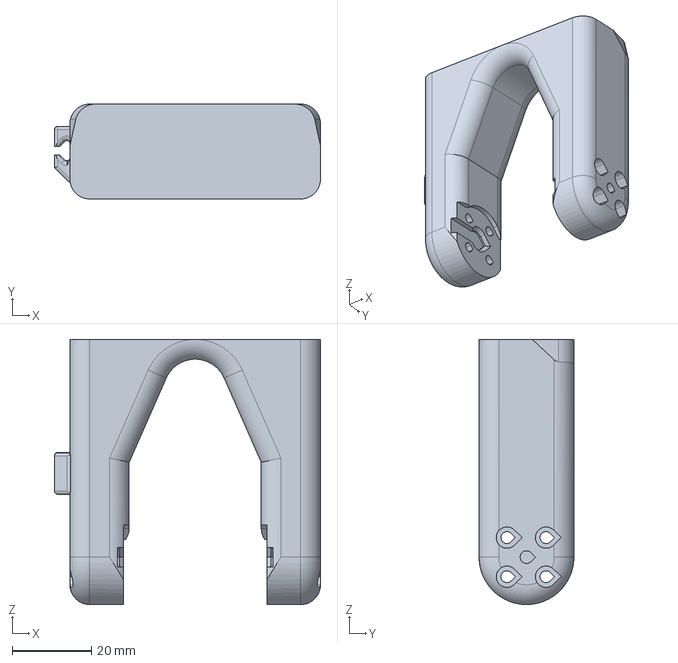
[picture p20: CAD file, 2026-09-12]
docs/design/so101/upper_fork_source.step
67.3 x 24.0 x 67.1 mm

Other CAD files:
docs/design/rear-leg/thigh-options/rear-leg-quadruped.step
docs/design/walking/foot_shank_right-v1.step
hardware/sim/meshes/front_right_lower.stl
docs/design/body-quadruped.step
docs/design/rear-leg/rear-leg-quadruped.step
docs/design/rear-leg/shank-left.step
docs/design/rear-leg/shank-right.step
docs/design/rear-leg/thigh-flat/shank_flush-left.step
docs/design/rear-leg/thigh-flat/shank_flush-right.step
docs/design/rear-leg/thigh-flat/thigh_flat-left.step
docs/design/rear-leg/thigh-flat/thigh_flat-right.step
docs/design/rear-leg/thigh-left.step
docs/design/rear-leg/thigh-options/rear-leg-upright.step
docs/design/rear-leg/thigh-options/thigh_body-right.step
docs/design/rear-leg/thigh-options/thigh_cheek-left.step
docs/design/rear-leg/thigh-options/thigh_cheek-right.step
docs/design/rear-leg/thigh-options/thigh_frame-left.step
docs/design/rear-leg/thigh-options/thigh_frame-right.step
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

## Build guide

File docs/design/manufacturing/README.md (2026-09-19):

# DEC-49/50 manufacturing evidence

All current STL variants have successful local slices and **`printable = assumed`**.
No physical print, fit, load test or validated TPU profile is claimed.
[Per-part orientation and support-removal review](../../part-design-review.md).

[Slice records](slices.json) identify each STL by SHA-256, its material, settings
hash, model-layer count, estimated filament/time and G-code hash. For each
part, `<part-name>-layers.png` shows four deposited-path sections: blue is the
part and orange is the nearest support layer (its separate Z is labelled). These PNGs open directly in iPad Files.

The shared printer profile is read from `../3d-printing/reference/`; it is not
copied into Koala. Project-specific overrides live in `hardware/print/`.
PETG uses snug supports **from the bed only** (`support_material_buildplate_only = 1`, the
house rule; plate 1 on 2026-09-19 was sliced without it and its M2 ear holes came out
blocked) and a brim; `manufacturing-petg-tree.ini` is the organic-support variant for the
v2 thigh and shank, one part per job. The TPU contact pad uses no
support; its taper avoids a flat cavity roof. TPU temperatures/feed remain
provisional until matched to the actual spool. G-code is a local review artefact
in `hardware/build/manufacturing/`, not a job submitted to the printer.

Regenerate locally from the repository root (requires PrusaSlicer):

```sh
uv run --directory hardware python -m koala_hardware.export
uv run --directory hardware python -m koala_hardware.manufacturing_slices
```

Supply `--profile /path/to/shared.ini` if the sibling checkout is elsewhere.
Re-export the BOM after slicing to include hash-matched estimates. Successful
slicing establishes an achievable toolpath, not reliable adhesion, clean
support removal, mechanical fit or strength in a physical print.

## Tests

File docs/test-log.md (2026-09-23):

# Test log

What printed parts actually showed, including "no change needed" — so the next
person knows a constant was **tested**, not guessed. Constants themselves live
in `hardware/src/koala_hardware/params.py`, tagged with their provenance.

Reference printer per DEC-14 (Ender-5 S1 / Klipper), PETG, the standing
general-purpose profile recorded in [`bom.md`](bom.md).

## 2026-09-21 — rear roll-spacing comment corrected (no print)

The `ROOT_ROLL_Y` expression already includes DEC-60's widened hip spacing,
but its trailing comment still said 64.05 mm. Evaluating it gives **66.3 mm**
per side, so centreline rear walking feet are **132.6 mm** apart at neutral
roll. The initial assistant estimate of 128.1 mm was wrong. Corrected the
comment and current walking documentation; no geometry or existing print
version changes. New `foot_shank` v1 remains unprinted/`unknown`.

## 2026-09-19 — forearm v2 STL roundoff persistence corrected (digital only)

The forearm BREP was valid, but exported STL coordinates for coincident vertices
could differ by floating-point roundoff. Validation already merged those
vertices with trimesh's normal defaults; the file on disk retained the raw
coordinates and left the slicer to repair the tiny cracks. `meshing.py` now
writes the same merged mesh it validates when those coordinates differ.
The merge tolerance and BREP are unchanged; this is an export correction,
not a printed-part geometry/version change. Forearms remain v2, `unknown`.

The regression checking STL closure after merging only identical coordinates
passes, and the full Python suite passes **65 tests**. Re-exported forearms and all **11 final review slices**
now report zero slicer diagnostics; their current STL/G-code and profile hashes
are in [slices.json](design/front-redesign/slices.json). Selected layer review
does not establish every layer start, physical support removal, fit or strength.
No printer was connected for these review slices.

## 2026-09-19 — shoulder cassette v1 nut-loading order corrected (digital only)

The four M3 frame nuts must be loaded into the **bare cassette before attaching
the A root**. With the root fitted, withdrawing the actual 2.4 mm hex nut by
2 mm intersects the root by 0.6766 mm³ at both inner locations (body Y17,
Z135/165); at 2.5 mm withdrawal the intersection is 2.0297 mm³. The previous
written assembly order put root fitting first and was wrong. Seated nuts
clear the root; this is a sequence correction, **not a geometry/version bump**.

The complete cassette/root/A package clears the torso and opposite A module
when removed **laterally outward**, sampled at 0/5/20/80 mm. Rearward pulling
instead reaches the dorsal rails. `test_shoulder_service.py` protects bare
nut loading, seated clearance and outward removal. The checks exclude the
moving carrier/downstream limb and real cables; they do not establish physical
nut retention, fitting or loaded strength. No part was printed for this check.

## 2026-09-19 — four CAD review defects corrected (digital only)

These are corrections of assistant-generated CAD/tooling, **not physical print
results**. They do not change the accepted SO-101 fit or root socket v1's
recorded physical status.

| Review finding | Correction and verification scope |
|---|---|
| Rear mounting screwdrivers intersect the retained torso flange | Torso v5 cuts Ø6.6 corridors; the frame audit now probes Ø6 drivers through the actual torso and both installed root modules/hardware. Previously it omitted the torso. |
| Split-group thigh rounding overwrites earlier fillets | Reselect edges from the updated solid for each operation. Thigh becomes v3, `unknown`; earlier v2 slices do not validate it. [Current views](design/parts/thigh-views.png). |
| Aggregate fingerprint misses relocated holes/nuts | Schema 2 records face geometry relative to the part bounds. The real root socket's 0.5 mm mounting-pattern shift is detected; whole-part translation and small numeric noise remain tolerated. Legacy ledgers require explicit migration from unmodified historical CAD. |
| Ledger update accepts lower versions | Reject any decrease before changing history or writing. Temporary-ledger regressions cover unchanged and changed geometry and confirm original bytes survive rejection; updates with changes require a note. |

The version-guard regression group passes **12 tests**. This entry records the
correction mechanisms and that focused result; completed assembly/export/viewer
outcomes are tracked in the [front revision record](design/front-redesign/README.md).
None establishes support removal, fastener fit, loaded travel or strength.

## 2026-09-19 — hip carrier v1 ×2 plate started (plate 2; in progress; result pending)

`koala-hip-carrier-x2.gcode` (left + right `hip_carrier` v1, STL SHA-256 eb5a282a / ad7843e2),
PETG, re-sliced after plate 1 with support from the bed only (no support at all results), Debian
prusa-slicer 2.5.0, estimate 6 h 42 min / 66 g. Started via Moonraker at the owner's request,
bed clear; bed target 80 °C. **Record here:** adhesion of the flat back, the horn-screw and
ear-hole roofs printed as unsupported bridges, fork fit on servo B's horn and idler, socket fit
for servo B, and whether `hip_carrier` moves to `proven`.

## 2026-09-19 — root socket v1 ×4 printed (plate 1): fit passes, four M2 ear holes blocked by support

First physical print of any DEC-53/55/56 part. `koala-root-socket-x4.gcode` (2 left +
2 right `root_socket` **v1** (`hardware/part-versions.json`), STL SHA-256 298f0eff / cbd58598 from the 2026-09-18 export), PETG,
base `ender5s1_petg.ini` + `hardware/print/manufacturing-petg.ini`, Debian prusa-slicer
2.5.0, slicer estimate 9 h 10 min / 89 g. Started via Moonraker at the owner's request
with the bed clear; bed target 80 °C. Plate 2 (`koala-hip-carrier-x2.gcode`) waits.
**Result (owner, 2026-09-19, 9 h 03 min, 29.3 m of filament):** all four parts pass for
main function. Defect: the four M2 clearance/counterbored ear-screw holes in each socket
are completely blocked. Cause: slicer, not geometry. `manufacturing-petg.ini` enabled snug
supports without `support_material_buildplate_only`, so PrusaSlicer grew support inside the
horizontal Ø2.2 holes; the 3d-printing repo's own decision names that setting as the answer
to "no supports in horizontal screw holes", and the house rule is support from the bed only.
The profile now sets it (and a tree variant exists for the v2 legs); the hip-carrier plate,
sliced the same way, is re-sliced before printing. **Actions:** clear the four printed
sockets' ear holes with a 2.2 mm drill before fitting servos, or reprint. `root_socket` v1 →
`proven` for geometry and fit, with that caveat, in `part-design-review.md`.

## 2026-09-12 — RCmall servo order arrived; STS3215 box contents (owner report, nothing measured)

12 × Feetech STS3215 12 V and 4 × STS3032M 6 V, the 2026-09-01 order in
[`sourcing.md`](sourcing.md), are in hand. The STS3215 packs were opened; the
owner reports the contents as the same hardware as the Waveshare box of 2026-09-07.

| Finding | Source | Consequence |
|---|---|---|
| **Two horns per servo — drive and idler**, metal | in the box | **Closes open check 7.** 12 servos → 24 horns, exactly the `Metal 9.9-square horn/idler` line of the [`bom.md`](bom.md) fastening schedule. Nothing to buy; [SPEC 11] "No Accessories" describes the bare part, not the RCmall retail pack |
| **M3×6 pan-head horn screws** | in the box | Same part as the Waveshare box (2026-09-08 row 9). `HORN_SCREW` holds for both vendors; head Ø and height not re-measured on the RCmall screws. Count per servo not recorded — the schedule needs 8 |
| **M2×6 self-tapping case screws** | in the box, owner's reading | The Waveshare box was recorded as **M2×5** (2026-09-07). Either the packs differ by 1 mm or one reading is off — caliper both before `SOCKET_M2_*` moves. Neither length reaches the walls measured 2026-09-07; longer screws are still needed. Count per servo not recorded — the schedule needs 4 |
| **No serial-bus adapter** in either 6-pack | in the box | The listing's "FE-URT-1 included" was wrong. ID assignment uses the family's Waveshare Bus Servo Adapter (A) or FE-URT-2 ([wk-robotics `common.md`](https://github.com/WayneKennedy/wk-robotics/blob/main/docs/common.md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)) |
| **The ordered STS3215 metal bracket set arrived; no bracket per servo** | in the shipment | The DEC-21 dimensional reference is in hand. Nothing changes for the printed brackets |

**STS3032M 4-pack (owner report, nothing measured):**

| Finding | Source | Consequence |
|---|---|---|
| **Fixed cable, one port** — not the two-port pass-through case of the STS3215 | in the box | The neck servos **cannot daisy-chain servo-to-servo**; the chain runs through the supplied boards instead ([`architecture.md`](architecture.md)) |
| **A small 3-port connector board, plus a separate cable to daisy-chain the boards** | in the box | Three ports read as servo lead + bus in + bus out, so each board is the servo's externalised second port and the boards chain with the supplied cable. That reading, and the number of boards and cables in the pack, are **inferred, not counted** — count them and note the connector type before designing the neck harness |
| **1 × aluminium drive horn + 3 × plastic horns per servo**, with all mounting screws | in the box | 3-RPS pushrod ends have a metal horn to fix to; the plastic horns are spares or alternatives. Screw sizes not recorded |
| No USB bus adapter | in the box | Same as the 6-packs; setup uses the family's Waveshare (A) or FE-URT-2 at **6 V** |

Open checks 1–4 and 6 below are still unmeasured; fourteen identical STS3215 cases
are now on the bench to answer them.

## 2026-09-11 — DEC-49/50 common carriers and unequal socket slots (unprinted)

All four roots now use `root_carrier_left/right`, two prints of each hand,
with the former front carrier's bevel removed. Both roll spacings are 149 mm;
rear motor mounts absorb the 0.1 mm per-side shift, preserving 220 mm track.
Direct substitution into the old rear mount clashed upright. Rear pitch cases
now point forward in the torso frame; the rear flange moves to Z=46 mm to clear
the common back and frame screw heads. The unresolved head placeholder is omitted.

The pinned SO-101 Upper arm STEP confirms distinct **14 mm drive / 18.5 mm
idler slots**, starting respectively 0/5 mm above the socket floor. The shared
primitive now matches those widths and starts, retains accepted ear/horn datums,
and no longer uses the Back width for both faces. The continuous lower idler
seat removes the old bore/strip tangency. Source/production planar-face
measurements and a [dimensioned image](design/so101/socket-slot-comparison.png)
are recorded in [socket-slots.json](design/so101/socket-slots.json).

- **17 designs / 24 export variants:** valid closed meshes within the bed rule;
  all current STL hashes have successful local slices. The chassis still uses
  24 physical prints. Common-carrier bed contact is approximately 2,236 mm²;
  the declared orientation uses only accessible local supports.
- **24 regression tests**, 62 complete assembly samples, 19 interface-rig angles
  and two nominal fallback-case checks pass. Bench servo insertion/ear-driver
  access and installed frame-bolt access remain checked.
- Browser/CAD alignment, both poses, slider recalculation and print/material
  tags pass. All twelve initial slider endpoints independently pass BREP checks.
  Upright grouped pitch limits are −101°/+58°; quadruped −27°/+91° in the current
  finite-resolution search. These are clearance aids, not physical servo limits.
- **Every part remains assumed printable.** No physical print, fitting, support
  removal, loaded travel or strength has been demonstrated for this revision.

[Current validation and STL hashes](design/cad-validation.json) ·
[Slice records and layer views](design/manufacturing/README.md).

## 2026-09-10 — DEC-48 manufacturing revision (local slicing; nothing printed)

Enclosing sockets, rounded/tapered fork roots and links, independently removable
root modules, flat-section forearms and keyed TPU contact pads now implement
the accepted layout. [Part review](part-design-review.md).

- **26 handed STL variants / 18 designs:** valid exports within the bed rule;
  successful local PrusaSlicer toolpaths, with exact STL/settings hashes and
  deposited-path PNGs in [manufacturing evidence](design/manufacturing/README.md).
  PETG uses accessible local supports/brims; the TPU pad slices without supports.
- **Printability remains assumed for every current part.** No current-revision
  physical print, material-quality, support-removal, fit or strength result.
  TPU settings are provisional until matched to the actual spool. Older SO-101
  fit and the pre-fix ladder result remain accepted, separate evidence.
- **CAD:** 62 full-assembly samples, 19 rig angles, separate fallback-reference
  checks, root-module bench driver/insertion and installed frame-bolt access.
  Twenty-two unit tests pass; the forearm export is checked on its broad back.
- **Viewer:** grouped travel searches at 0.25° resolution with a 1° reserve,
  changing with pose and other joint settings. All twelve initial slider
  endpoints independently pass BREP collision checks. Browser/CAD parity,
  reset and per-part material/printability display pass in both poses.

[Current validation snapshot](design/cad-validation.json). No print was
submitted; all slicing ran on the workstation, not the printer controller.

## 2026-09-08 — calipers and photos: the ST3215 as it really is (nothing printed)

Terminology per [`soarm-joint-pattern.md`](soarm-joint-pattern.md): **Front**
(drive horn), **Back** (idler and connectors), **Bottom** (the end it stands on;
ears near it), **Top** (end nearest the output axis), **Sides**. Height is from
the Bottom. Cheap calipers, ±0.3. Everything here moved a constant to
`[MEASURED]` or corrected a doc.

| # | Measurement | Value | Consequence |
|---|---|---|---|
| 1 | Drive horn outer face → idler outer face (clevis span) | **36.4** | `SOCKET_HORN_SPAN` 37.5 → 36.4. Also 36.4 on the printed `Rotation_Pitch` fork and in its STEP (arm faces Y 10.0 / 46.4). The 37.5 was a probing error in the review (an axis probe read a centre recess as the arm face); upstream's CAD was right, as was the SO-100 bracket reading of 2026-09-02 |
| 2 | Idler: total thickness / tapped body / boss | **3.1 / 2.1 / 1.0**, boss **inward** onto the servo; tapped M3 on the 9.9 square like the drive horn | both horns present flat outer faces when fitted; plates bear on flat metal |
| 3 | Idler outer face above the seat it sits on | **3.1** | sits flat; the servo's boss stands **0.7** proud of the idler face — the Back plate's blind centre recess (upstream Ø6 × 1.0) clears it |
| 4 | Front ↔ Back, horn/idler seats | **28.8** | `SOCKET_HORN_SEAT_X` |
| 5 | Front ↔ Back, ear faces (M2 holes) | **31.8** | `SOCKET_EAR_X`; the SO-101 cradle walls boss inward to exactly this at the holes (STEP 15.6 + 16.2) |
| 6 | Front ↔ Back, widest faces | **~34.8** | the pocket; `SOCKET_CASE_X` 34.9 stands (proven by fit) |
| 7 | Front side steps from the seat: ear / widest / drive horn face | **1.5 / 2.5 / 4.3** | 28.8 + 3.1 + 4.3 = 36.2 vs 36.4 measured — closes within the tool |
| 8 | Back side step, seat → widest | **3.5** | **not symmetric**: seat mid-plane is 0.5 toward the Front of the pocket centre → `SOCKET_SEAT_OFFSET = 0.5`, idler face **−17.0**, drive face **+19.4**, track 238.2 |
| 10 | Back face, regions along the height from the Bottom (photos IMG_6993/6994, lettered) | **A 0–5.3, B 5.3–18.8, C 18.8–35.8, D 35.8–46.0; E (case length) 45.4** | A+B+C+D = 46.0 vs 45.4, within the tool. The C/D boundary is the **output axis** (45.4 − 10.2 = 35.2; spec puts it at 22.6 + 12.5 = 35.1 ✓). A carries the Bottom M2 pair at the corners; B is the region with the recessed rectangular panel; the **connector bay starts at the B/C line (18.8) and runs to ~24.5**, two connectors facing out along the axis, with a second M2 pair flanking it at ~22; the Ø8 boss sits in a raised round pad at the axis. Depth planes: A = ear plane, B = widest, and — photo IMG_6995 with the idler fitted — **the Ø20 seat is a raised round pad that the idler covers exactly**, so the general faces of C and D lie *below* the seat plane. `socket_reference()` now models this profile, with C/D conservatively at the seat plane. Front region lengths assumed equal `[VERIFY]` |
| 9 | Horn screws supplied in the Waveshare box | **M3×6 pan head, head Ø5.2 × 2.0** | `HORN_SCREW*` `[SUPPLIED]`. Upstream's fork counterbores do not fit them. With a 3.5 web (upstream's, and 6 − 3.5 = 2.5 into a horn whose tapped body is 2.1) the plate needs a ≥Ø6 × ≥2.5 counterbore, so the horn pad is ~6 thick, not 3.5. The RCmall Feetech packs ship the same M3×6 pan head (owner report 2026-09-12; head not re-measured) |

**The audit failure has moved to the right place.** With the full-width box it
failed on the idler face being 0.4 inside the widest Back plane (229 mm³).
With the measured profile in `socket_reference()` (row 10) that clears, and it
now fails on the two centre features the bench identified: the **drive horn's
pan head** (Ø5.2 × 2.0) into the flat Front plate — 26.4 mm³ — and, once past
that, the **servo boss** (Ø8 × 0.7) into the flat Back plate — 35.2 mm³, which
is exactly π·4²·0.7. Both are DEC-34 plate defects already on the corrections
list (Front countersink, Back blind recess); left failing until the plates are
fixed.

**Case reference switched to a vendored STEP, same day.** The maintainer
supplied `STS3215_c.step` (FreeCAD model, author and licence to record;
`hardware/vendor/st3215/README.md`). Its shape matches the servo — centred
pads, ear plane, connector bay at 18.7–23.6, seat pads, Top step — and its
dimensions match the calipers within 0.3 except the horn stack (span 37.25
against 36.4). `servo_iface.case_model()` loads its three case solids into the
socket frame (Bottom at Z=0, Front +X, pocket centred by a 0.4 shift); the
horns, idler, boss and pan head stay on the measured constants. The
hand-built stepped profile remains as the fallback when the file is absent.

Also established the same day:

- The printed forks are **counterbored (teardrop) over M3 clearance holes**;
  screws seat on the plastic and thread into the tapped horns. **The
  counterbores are too small for the M3 horn screws supplied with the Waveshare
  servos.** koala's counterbore must fit those heads — diameter and height to
  measure.
- Retention is **friction plus four M2 self-tappers, two through the Front wall
  side and two through the Back wall side**, into the servo's ears.
- **Connector bay on the Back**, immediately below the idler disc, two
  connectors facing out along the axis; the cable leaves along the axis and
  turns down the outside (IMG_6990/6991). Upstream's cradle and collar have **no
  cable window** (STEP probe), so DEC-34's floor slot and collar slot are
  inventions. Two more M2 holes flank the idler disc on the Back, ~20 mm above
  the ones the collar uses. *To confirm:* bay height from the Bottom; ears at
  2.2 / 5.8 with holes.
- Upstream `Motor_holder_Base`'s Front boss has a **plain Ø4.0 bore with no
  seat**, unlike the other three M2 positions. *To confirm:* what the servo
  presents there.

The items DEC-33 waived (pocket, lug positions, hole stack, plate geometry) are
now read from the printed-part STEPs instead — the maintainer's point that
parts proven by fit carry the interface. What no part file can give is where
the servo sits inside it, which is what the readings above supply.

## 2026-09-08 — DEC-34 digital prototype checks (nothing printed)

Replaced both discarded lower-body builders. Export passes the existing bed,
connected-solid and surface checks; explicit handed STLs are generated.
The audit checks the socket and bores, 27 local roll/hip/knee poses with
nominal horn/carrier/motor/lug heads and nuts, and 81 opposing-leg pose pairs.
The browser regression rendered the assembly and matched left/right hip/knee
motion to CAD within 0.1 mm; eight unit tests passed. Scope and remaining
uncertainties are in [`cad-restart-design.md`](cad-restart-design.md).

Read-only Moonraker queries on 7 September and at 00:01 BST on 8 September
returned **printing**. No slicing or print was
started. The five `coupon_socket_*` parts are the next fit rig; they include
the same registered cheeks and crossbar interface as the legs. None of these
digital results establishes physical fit, unsupported-layer behaviour or
strength.

## 2026-09-07 — maintainer confirms SO-101 fit in PLA+ and PETG

The maintainer reports that the standard ST3215 servos fit the SO-101 parts
perfectly in **both PLA+ and PETG**, and explicitly removes the requirement
for repeat gauging or caliper measurements before redesign (DEC-33).
The earlier local `3d-printing` entry documents the PLA+ Gauge_0 test;
the PETG evidence here is the maintainer's direct report. No print settings,
new caliper readings or individual PETG job identifiers were supplied.

Adopt the Gauge_0 nominal pocket with zero added servo clearance
(`SOCKET_CLEAR` in `params.py`). This does not validate generic non-servo
pockets, new retention details, or the new joint's loaded behaviour.
The new primitive's lug positions and horn span remain tagged `[STEP]`.

## 2026-09-07 — SO-101 joint pattern, measured from upstream CAD (desk study; nothing printed)

Prompted by the maintainer's SO-101 build: the koala drafts never followed the
mounting pattern DEC-21 named. Upstream's assembly and part STEPs were measured
with booleans and sections; full record and numbers in
[`soarm-joint-pattern.md`](soarm-joint-pattern.md). What changes for koala:

| Finding | Source | Consequence |
|---|---|---|
| Retention is **cradle + collar + 4 M2 self-taps into the servo's lugs**, then a **clevis on both horns** | Base/Base_motor_holder, Rotation_Pitch/Motor_holder_Base, Upper_arm | DEC-21 amended to say so; both drafts logged as breaches; the restart builds it as one primitive |
| Lug holes sit at **~2.1 mm from the rear face on the back face and ~5.8 mm on the horn face** | Ø2.0 holes in Base roof/floor and Rotation_Pitch walls | `SERVO_TAB_X = −20.7` matches one face only → the open check below gains a second number |
| Case-screw hole in plastic is **Ø2.0 clearance, ~2.2 long, counterbored above** | all four parts | `SERVO_TAB_HOLE` 4.0 → 2.0; the M2×5 "too short" finding is solved by counterboring, not longer screws |
| Pocket **34.9 × 24.7, zero clearance**, press fit in PLA+ on this printer | `Gauge_0`; `3d-printing` print-log 2026-09-06/07 | `CLEAR_POCKET` (0.25, PETG) gets its value from printing `Gauge_0` in PETG, not from a guess |
| Horn pattern **9.9 square**, plates 3.5 thick, holes Ø3.0–3.2, idler bolted too | Upper_arm, Rotation_Pitch | confirms `SERVO_DRIVE_SQ` and the 2026-09-02 idler finding; `CLEAR_HOLE_M3 = 3.4` (measured) stays |
| Upstream's assembly **servo model overlaps its own cradle wall** by ~2 mm | assembly STEP | second servo model found wrong; measure printed parts and real servos only |

**Added to the open caliper checks below (2026-09-02 §Open):** 8. lug offsets from
the rear face on *both* faces; 9. lug pilot depth; 10. horn and idler stand-off
and the full horn stack for the clevis span.
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

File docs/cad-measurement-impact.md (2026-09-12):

# Measurement impact assessment — 2026-09-08

**Historical assessment of `f541600`.** [DEC-40](cad-integrated-design.md)
implements the corrections in the integrated four-limb chassis. The findings
below describe the pre-correction geometry, not the current build.
The latest measurements invalidate the earlier socket clearance and fastening
claims. Updating the horn-span constant alone has also opened a gap in the hip
carrier. The six-servo architecture and 100/100 mm links remain a usable starting
point; their revised packaging has not passed the full motion audit.

## Baseline and evidence

Fetched and fast-forwarded `main` from `3893b88` to `f541600`: 22 commits.
The main changes are:

- `c46d1d6` / `7d5fa9f`: fitted horn span is 36.4 mm; 37.5 was a probing error.
- `1e9ac89` / `14be251`: printed-part STEP evidence corrects retention, plate
  faces and head pockets; the SO-101 elbow saddle is a separate exception.
- `ad811e9` through `aa23fb7`: fitted idler, centre boss, supplied screw heads,
  asymmetric case planes, face terminology and connector-bay measurements.
- `1022303` / `f19356f` / `ab12a26`: reference geometry gains the stepped case,
  centred raised pads and optional maintainer-supplied STEP case.
- `95206c0` / `3648f2d` / `f541600`: press-fit overlap allowance, disjoint
  boolean handling and removal of the third-party model from version control.
- `91b663b`: blake becomes the canonical viewer host (DEC-35).

Measurement provenance and remaining uncertainty belong in
[`test-log.md`](test-log.md) and [`soarm-joint-pattern.md`](soarm-joint-pattern.md).
This assessment uses their current conclusions, including withdrawn photo
interpretations, rather than treating every intermediate commit as authoritative.
The existing confirmed SO-101 fit remains valid; no repeat-gauge prerequisite
is reinstated. It did not establish that the DEC-34 primitive reproduced SO-101.

## Findings and correction scope

| Priority | Finding at `f541600` | Required response |
|---|---|---|
| Blocking | Front plate intersects the centre pan head by **26.389 mm³**. Back plate intersects the measured boss by **35.186 mm³** with the fallback reference, **46.420 mm³** with the STEP reference. | Replace the incorrect Ø20.5 horn recess with flat horn contact; provide Front centre-head clearance and a Back blind boss recess. Both retain four horn-square fixings. |
| Blocking | `V2_HIP_STEM_X` remains 22.75, while the Front roll-cheek outer face moved to 22.10. Solid-to-solid distance is **0.65 mm**. | Derive the stem mating datum from the final cheek geometry. Verify bearing contact and compression through the complete carrier stack; aligned screw bores alone are insufficient. |
| Blocking | Cradle takes both Back ears and collar both Front ears. Upstream splits them by Side position, with one Front and one Back ear on each part. Walls still end at the widest-case planes rather than bossing inward to the ear faces. | Rebuild the shared cradle/collar retention and remove the invented boss lanes. Propagate through integral roots and supports; demonstrate Side insertion and collar assembly. |
| Blocking | At the nominal ear centres, the current wall-to-ear gaps are **1.05 Front / 2.05 Back mm**. M2x5 minus a 2.2 mm seat and these gaps leaves only **1.75 / 0.75 mm** nominal penetration, not 2.8. | Bring bosses to the ear planes; use the corrected printed-part lug positions and seat geometry. Confirm actual engagement and absence of bottoming on the rig. |
| Required | Horn-square head pockets are absent. `audit.horn_heads()` still models proud Ø5.5 × 3 cap heads, despite the supplied Ø5.2 × 2 pan-head constants. | Use the measured hardware and the brief's ≥Ø6 × ≥2.5 counterbores over a 3.5 mm web. Recheck pad strength, print orientation and screw stack. M3x6 projects 2.5 mm beyond that web against a 2.1 mm tapped idler body; bottoming remains a rig question. |
| Required | `SOCKET_BAY_Z` is unused by the keepouts. Current cable probes exit through the Bottom/open Side; the connectors face out from the Back. A Ø28 Back plate reaches Z21.115, overlapping the bay's height band by **3.385 mm**. | Replace the cable envelope with the actual Back exit and an articulated service loop. Ø24 alone still overlaps the height band by 1.385 mm: check connectors explicitly and trim the plate if needed. Height overlap is a clearance concern, not proof of a connector-solid collision. |

Ear-gap arithmetic uses the pocket planes ±17.45 and ear planes +16.4/−15.4
from the measured +0.5 seat offset. These are nominal calculations, not thread
pull-out predictions or additional caliper measurements. The corrected lateral
hole centres are ±10.25 rather than ±10.4; Back heights are 2.2–2.3 rather
than 2.1, while the existing Front 5.8 lies within the upstream 5.7–6.1 range.
The fourth upstream collar hole's missing M2 seat remains a bench question;
do not copy an unexplained through-hole as a verified fastening stack.

The brief requests a Front centre countersink while DEC-25 forbids countersinks
in plastic. Resolve this explicitly in the correction: the centre feature clears
an already installed pan head; it must not become a conical load-bearing screw
seat. A flat-bottom clearance pocket is a candidate, subject to remaining web
and printability. Counterbores on the opposite plate face also require a fresh
orientation/overhang check.

## Propagation beyond the socket

All six lower-body servo positions are affected: pelvis roll roots, both hip
pitch cradles, knee cradles within the thigh cores, six collars and twelve horn
cheeks. All five joint-rig parts need regeneration. Changed mating faces affect
hip crossbars, thigh/shank crossbars, registration shoulders, the hip stem,
motor-plate placement, fastener grips and hardware envelopes.

Current derived values below describe the **uncorrected implementation**, not
approved dimensions for the replacement:

| Quantity | `3893b88` | `f541600` |
|---|---:|---:|
| Horn outer-face span | 37.5 | 36.4 |
| Back / Front horn face X | −17.45 / +20.05 | −17.00 / +19.40 |
| Crossbar mating-face span | 36.7 | 35.6 |
| Proximal fork grip, including cheeks | 43.7 | 42.6 |
| Hip carrier head seat to outer Back cheek | 52.95 | 52.50 |
| Motor-plate seam grip | 46.7 | 45.6 |
| Wheel-centre track | 239.5 | 238.2 |
| Neutral motor end gap | 55.5 | 54.2 |

The intermediate documented track 237.3 and hip grip 51.85 missed the later
asymmetric face shift. Removing the 0.8 mm Front recess alone would make the
bridge span 36.4 and track 239.8, assuming all other datums stay fixed. That is
a sensitivity calculation, **not the final layout**: thicker horn pads and
the carrier contact repair must be designed together before resampling motion.

Nothing in these measurements requires changing the DOF count, link lengths,
nominal hip/knee angles or wheel/motor bought-part specification. The 283.2 mm
nominal deck height and analytical sagittal torque screen retain their stated
assumptions. Printed mass, lateral clearances and loaded performance must be
reassessed after the geometry changes. No direct e-tray redesign is identified.

## Checks run and gaps in validation

On ivory, against `f541600`, using `uv run` from `hardware/`:

- `python -m koala_hardware.audit`: **fails** at `rig drive -90/case:
  26.389 mm³ overlap`, both without the STEP and with the same 4,372,667-byte
  ignored model present on blake. The model was copied privately for this
  assessment; it remains untracked. See its [provenance](../hardware/vendor/st3215/README.md).
- Independent plate/reference intersections at −90…90° in 10° steps confirm
  the table's Front and Back failures at **all 19 angles** with each reference.
  Ø8 boss diameter and Front case-region heights remain unverified.
- Layout, connected-solid/bed-envelope and pelvis-symmetry checks preceding
  the audit failure passed. `audit.check_mounting()` also passed independently,
  despite the measured 0.65 mm carrier gap: its probes check holes, not contact.
- `python -m unittest discover -s tests`: **8 passed**. These cover sizing and
  the printability classifier, not the corrected servo interface.
- The full 27-pose and 81 opposing-leg audits were **not reached**. No new export,
  surface screen, browser/CAD parity, slicing, printing or load test is claimed.

**Reference composition also needs correction.** The imported bare case already
contains a central Back projection: its intersection with the Back plate is
27.310 mm³, reaching X=−18.2 (1.2 mm beyond the measured idler face). Adding a
measured 0.7 mm boss by union does not remove that imported projection. This
explains the STEP's larger Back overlap; it is not a new physical measurement.
Isolate or replace this feature so the reference actually follows the measured
boss envelope before interpreting the remaining collision volumes.

The STEP case/cradle overlap is 8.930 mm³ (fallback: zero), below the new
50 mm³ socket press-fit allowance. The full-pose loop still applies 0.01 mm³
to these reference/print pairs, so its treatment of intended contact is
inconsistent. Localize allowed contact to the intended pocket regions and
apply it consistently; do not relax plate, hardware or moving-part checks.
Neither reference includes a complete plugged-in loom. A successful export
or viewer rebuild is therefore not evidence of an audit pass.

## Repair sequence and acceptance

1. Correct the shared primitive from the latest printed-part pattern and
   measured hardware: retention, ear seats, flat horn faces, centre clearances,
   head pockets and Back connector envelope. Keep Gauge_0's pocket unchanged.
2. Derive all mating datums, including the hip stem, from those interfaces.
   Recalculate grips and screw engagement before settling hardware lengths.
3. Add focused checks for required bearing contact, ear-seat gaps, actual
   screw-head seating and Back connector clearance; reconcile the imported
   boss with the measured reference and intended press-fit contact between
   primitive and assembly audits.
4. Regenerate the rig and dependent structures; rerun export/surface checks,
   both reference audits, motion samples and browser/CAD parity. Regenerate the
   BOM from metadata and update dimension/assembly claims only from that result.
5. Follow the existing one-joint fit → one leg → pair → load/creep sequence
   (OQ-12/13). This assessment neither changes DEC-33 nor accepts a physical part.

The canonical viewer remains on blake under DEC-35. Its service rebuilds only
on restart and can retain an older scene after a failed build; a visible scene
does not establish that it represents the latest commit. No viewer service was
changed during this assessment.

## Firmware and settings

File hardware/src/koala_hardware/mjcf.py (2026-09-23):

"""MuJoCo MJCF of the four-foot walking build (DEC-62), from the CAD's solids and kinematic frames.

    uv run python -m koala_hardware.mjcf              # sim/koala_walking.xml + .json + meshes/*.stl
    uv run python -m koala_hardware.mjcf --crude      # sim/koala_walking_crude.xml: capsule visuals, same inertia
    uv run python -m koala_hardware.mjcf OUT.xml      # elsewhere (meshes/ beside it)

Bodies are the CAD's rigid groups (assembly.nominal_details): every print of a group plus the servo
case(s) its socket frames place, unioned and exported as one visual STL per body in that body's
joint frame. Inertia is computed per solid from the BREP and summed per body: prints at an effective
density (the slicer's filament volume where a docs/design/*/slices.json record matches the current
STL hash, exactly as the BOM does; else solid PETG/TPU, an upper bound), each servo as a
SERVO_MASS box of the case dimensions at its socket. Omitted: fasteners, horn/ear screw heads,
the unbought neck-servo envelopes, battery, electronics, head and cables. Contacts are the four
sphere feet and a torso box for fall detection. Joint ranges are the viewer's shared-slider
clearance bounds (no per-joint search exists), and the actuator is Open Duck's BAM fit of the
7.4 V STS3215 until the 12 V unit is identified (wk-robotics docs/status.md, "A sim model of
koala-bot's four-foot build"). Nothing here is verified against hardware. Loading the output needs
MuJoCo, which is not a dependency of this package: mjcf_check.py runs from any venv that has it.
"""
import hashlib, json, sys, tempfile
from pathlib import Path
import numpy as np
from build123d import Box, Pos, Plane, Align, CenterOf, Compound, mirror, export_stl
from OCP.BRepTools import BRepTools
from koala_hardware import assembly as A, body_plan as B, params as P
from koala_hardware.export import DENSITY                       # g/cm3 PETG 1.27, TPU 1.2 (provisional)
from koala_hardware.meshing import export_mesh
from koala_hardware.parts import configuration_specs, links, torso

ROOT = Path(__file__).resolve().parents[2]
SLICE_RECORDS = [ROOT.parent / 'docs/design' / d / 'slices.json' for d in ('walking', 'manufacturing', 'front-redesign')]
MM = 1e-3
SERVO_G = P.SERVO_MASS                                          # 55 g [SPEC], params.py
SERVO_CASE = (P.SOCKET_CASE_X, P.SOCKET_CASE_Y, P.SOCKET_CASE_L)  # 34.9 x 24.7 x 45.23 mm, socket frame (servo_iface.py)
MESH_TOL = (0.2, 0.6)                                            # export_stl linear mm, angular rad: visual only
# Shared-control clearance bounds in the walking pose (degrees, relative to the pose),
# docs/design/walking/viewer-endpoints.json "initial_pose_bounds.walking". These are
# sampled CAD clearances for ONE shared slider driving all limbs, not servo limits.
RANGE = {'pitch': (-43.5, 107.5), 'roll': (-16.0, 29.25), 'bend': (-61.25, 89.25)}
# Placeholder actuator: Open Duck's BAM fit of the 7.4 V STS3215
# (Open_Duck_Playground/.../open_duck_mini_v2.xml:45-49). 12 V fit is plan step 1.
SERVO_CLASS = dict(damping=0.56, frictionloss=0.068, armature=0.027, kp=13.37, force=3.23)
# nominal_details name (hand suffix stripped) -> BOM export name (export.py variants)
EXPORT_NAME = {'pelvis_socket': 'root_socket', 'shoulder_socket': 'root_socket', 'rear_carrier': 'hip_carrier',
               'rear_thigh': 'thigh', 'rear_shank': 'foot_shank', 'rear_contact_pad': 'front_contact_pad',
               'front_carrier': 'shoulder_carrier', 'front_upper_arm': 'upper_arm', 'front_forearm': 'forearm'}
HANDED = {'root_socket', 'hip_carrier', 'thigh', 'foot_shank', 'shoulder_carrier', 'upper_arm', 'forearm', 'shoulder_mount'}
JOINT_NAMES = {'rear': {'pitch': 'hip_pitch', 'roll': 'hip_roll', 'bend': 'knee'},
               'front': {'pitch': 'shoulder_pitch', 'roll': 'shoulder_roll', 'bend': 'elbow'}}


def export_name(item):
    """nominal_details item name -> (BOM export name incl. hand, material)."""
    hand = ''
    for suffix in ('_right', '_left'):
        if item.endswith(suffix):
            item, hand = item[:-len(suffix)], suffix
    if item.startswith('tray_spacer'):
        item = 'tray_spacer'
    base = EXPORT_NAME.get(item, item)
    return base + (hand if base in HANDED else ''), ('TPU' if 'contact_pad' in base else 'PETG')


def slicer_masses(names):
    """{export name: record} where the current STL (built exactly as export.py builds it) hashes to a slice record."""
    records = {}
    for path in SLICE_RECORDS:
        if path.exists():
            for r in json.loads(path.read_text())['parts']:
                records.setdefault(r['stl_sha256'], (r, f'{path.parent.name}/{path.name}'))
    found = {}
    with tempfile.TemporaryDirectory() as tmp:
        for spec in configuration_specs('walking'):
            if spec['name'] not in {n.removesuffix('_right').removesuffix('_left') for n in names}:
                continue
            oriented = spec['orientation'] * spec['part']
            variants = ([(f"{spec['name']}_right", oriented), (f"{spec['name']}_left", mirror(oriented, Plane.XZ))]
                        if spec.get('handed') else [(spec['name'], oriented)])
            for name, solid in variants:
                if name not in names:
                    continue
                solid = Pos(0, 0, -solid.bounding_box().min.Z) * solid
                f = Path(tmp) / f'{name}.stl'
                export_mesh(solid, f)
                hit = records.get(hashlib.sha256(f.read_bytes()).hexdigest())
                if hit:
                    r, src = hit
                    found[name] = {'cm3': r['filament_cm3'], 'source': src, 'sha256': r['stl_sha256'][:12]}
    return found


def props(shape):
    """Volume (mm3), centroid (mm) and volume-inertia about the centroid (mm5) of a BREP shape."""
    v = shape.volume
    c = np.array(tuple(shape.center(CenterOf.MASS)))
    return v, c, np.array(shape.matrix_of_inertia)              # OCC GProp: already about the centroid


def servo_boxes(pose_name):
    """{reference servo item name: box solid, world mm} for all twelve limb servos."""
    box = Box(*SERVO_CASE, align=(Align.CENTER, Align.CENTER, Align.MIN))
    out = {}
    for name, _owner, frame in A.socket_frames(pose_name):
        right = frame * box
        out[name] = right
        out[name.replace('_right', '_left')] = mirror(right, Plane.XZ)
    return out


def collect(pose_name='walking'):
    """Per MJCF body: its solids (world mm), each with a mass-model role, plus the body's joint origin."""
    jd = A.joint_data(pose_name)
    pose = B.poses()[pose_name]
    hip = np.array([pose['rear'].root.x, 0.0, pose['rear'].root.z])
    bodies = {'torso': {'origin': hip, 'parent': None, 'joint': None, 'items': []}}
    group_of = {'fixed': 'torso', 'rear_fixed': 'torso', 'front_fixed': 'torso'}
    for key in ('rear', 'front'):
        d = jd[key]
        for side, sname in ((1, 'right'), (-1, 'left')):
            prev = 'torso'
            for stage, part in zip(d['order'], ('carrier', 'upper', 'lower')):
                body = f'{key}_{sname}_{part}'
                centre = np.array(d[stage]) * [1, side, 1]
                axis = side * np.array(d['roll_axis']) if stage == 'roll' else np.array([0., 1., 0.])  # mirrored roll: same axis, opposite sign
                bodies[body] = {'origin': centre, 'parent': prev, 'items': [], 'side': side, 'key': key,
                                'joint': {'name': f'{key}_{sname}_{JOINT_NAMES[key][stage]}', 'axis': axis, 'range': RANGE[stage]}}
                group_of[(f'{key}_{stage}', side)] = body
                prev = body
    boxes = servo_boxes(pose_name)
    for name, shape, _colour, group, side in A.nominal_details(pose_name):
        body = group_of.get(group) or group_of[(group, side)]
        if name.startswith('reference_'):
            if name in boxes:
                bodies[body]['items'].append({'name': name, 'role': 'servo', 'visual': shape, 'mass_shape': boxes[name]})
            continue                                              # screw heads, fixings, neck envelopes: omitted
        bodies[body]['items'].append({'name': name, 'role': 'print', 'visual': shape, 'mass_shape': shape})
    for key in ('rear', 'front'):
        limb = pose[key]
        y = P.BODY_SHOULDER_WIDTH_MM / 2 if key == 'front' else links.rear_axis_y()
        for side, sname in ((1, 'right'), (-1, 'left')):
            bodies[f'{key}_{sname}_lower']['foot'] = np.array([limb.axle.x, side * y, limb.axle.z])
    return bodies


def mass_model(bodies):
    """Fill each item's mass_g and each body's mass, com (world mm) and inertia about it (kg m2). Returns the per-print table."""
    prints = {it['name']: export_name(it['name']) for b in bodies.values() for it in b['items'] if it['role'] == 'print'}
    sliced = slicer_masses({e for e, _ in prints.values()})
    table = {}
    for b in bodies.values():
        total = 0.0; first = np.zeros(3); inertia = []
        for it in b['items']:
            v, c, ic = props(it['mass_shape'])                    # mm3, mm, mm5
            assert v > 0, it['name']
            if it['role'] == 'servo':
                m, src = SERVO_G, 'servo box'
            else:
                e, material = prints[it['name']]
                if e in sliced:
                    m, src = sliced[e]['cm3'] * DENSITY[material], f"slicer {sliced[e]['source']}"
                else:
                    m, src = DENSITY[material] * v / 1000, f'solid {material}'
                table[e] = {'mass_g': m, 'solid_g': DENSITY[material] * v / 1000, 'source': src, 'material': material}
            rho = m / v                                           # g/mm3, uniform over the solid
            it.update(mass_g=m, density_g_cm3=rho * 1000, source=src)
            total += m; first += m * c; inertia.append((m, c, rho * ic))  # g mm2
        com = first / total
        i = sum(ic + m * ((d := c - com) @ d * np.eye(3) - np.outer(d, d)) for m, c, ic in inertia)
        b.update(mass_g=total, com=com, inertia=i * 1e-3 * MM**2)  # g mm2 -> kg m2
    return table


def union(items, key='visual'):
    u = None
    for it in items:
        for s in it[key].solids():
            u = s if u is None else u + s
    return u


def write_mesh(bodies, name, path):
    b = bodies[name]
    try:
        shape = union(b['items']); kind = 'union'
    except Exception as e:                                         # boolean failure: ship the shells unfused
        shape = Compound(children=[s for it in b['items'] for s in it['visual'].solids()]); kind = f'compound ({e})'
    shape = Pos(*(-b['origin'])) * shape
    BRepTools.Clean_s(shape.wrapped)                               # drop any finer cached triangulation
    export_stl(shape, str(path), tolerance=MESH_TOL[0], angular_tolerance=MESH_TOL[1])
    return kind, path.stat().st_size


def v3(p): return ' '.join(f'{x*MM:.6f}' for x in p)
def ax(a): return ' '.join(f'{x:.6f}' for x in a)


def inertial(b):
    i = b['inertia']
    return (f'<inertial pos="{v3(b["com"] - b["origin"])}" mass="{b["mass_g"]*1e-3:.5f}" '
            f'fullinertia="{i[0,0]:.3e} {i[1,1]:.3e} {i[2,2]:.3e} {i[0,1]:.3e} {i[0,2]:.3e} {i[1,2]:.3e}"/>')


def build(out, crude=False, pose_name='walking'):
    out = Path(out); out.parent.mkdir(parents=True, exist_ok=True)
    pose = B.poses()[pose_name]
    bodies = collect(pose_name)
    table = mass_model(bodies)
    meshes = {}
    if not crude:
        (out.parent / 'meshes').mkdir(exist_ok=True)
        for name in bodies:
            meshes[name] = write_mesh(bodies, name, out.parent / 'meshes' / f'{name}.stl')
    sliced = sorted(e for e, r in table.items() if r['source'].startswith('slicer'))
    solid = sorted(e for e, r in table.items() if r['source'].startswith('solid'))
    total = sum(b['mass_g'] for b in bodies.values())
    com = sum(b['mass_g'] * b['com'] for b in bodies.values()) / total
    theta = pose['body_angle']
    L = []; w = L.append
    w(f'<mujoco model="koala_walking{"_crude" if crude else ""}">')
    w(f'  <!-- Generated by koala_hardware/mjcf.py from koala-bot CAD, {pose_name} pose (DEC-62). Do not hand-edit. -->')
    w('  <!-- visuals: ' + ('CRUDE capsules between joint centres, not the prints' if crude else
      f'one STL per body in meshes/ (mm, scaled), the body\'s prints unioned with its servo case(s) at the CAD socket frames; tolerance {MESH_TOL[0]} mm / {MESH_TOL[1]} rad') + ' -->')
    w(f'  <!-- inertia: per solid from the CAD BREP, summed per body. Prints at an effective density: slicer filament volume x PETG {DENSITY["PETG"]} / TPU {DENSITY["TPU"]} g/cm3 where the current STL hash matches a docs/design/*/slices.json record ({", ".join(sliced)}); otherwise SOLID density, an upper bound ({", ".join(solid)}). Each servo a {SERVO_G:g} g [SPEC] uniform box {SERVO_CASE[0]} x {SERVO_CASE[1]} x {SERVO_CASE[2]} mm at its socket. -->')
    w(f'  <!-- omitted mass: fasteners, horn/ear screw heads, neck servo envelopes (unbought), battery, electronics, head, cables. Total {total/1000:.3f} kg; CoM world {v3(com)} m in this pose. -->')
    w('  <!-- contacts: four sphere feet (contype 1) and a torso box (contype 2) for fall detection only; link meshes do not collide -->')
    w('  <!-- joint ranges: the viewer\'s shared-slider clearance bounds (viewer-endpoints.json), one slider per axis for all limbs; no per-joint search exists. NOT servo limits -->')
    w('  <!-- actuator: Open Duck 7.4 V BAM placeholder, NOT the 12 V unit -->')
    w('  <!-- CAD "right" is +Y (params.py body +Y right). With X forward / Z up that is the robot LEFT in a right-handed frame; names below follow the CAD. -->')
    w('  <compiler angle="degree" meshdir="meshes"/>')
    w('  <option timestep="0.002"/>')
    w('  <visual><global offwidth="1280" offheight="960"/></visual>')
    w('  <default>')
    w('    <default class="sts3215">')
    w(f'      <joint type="hinge" damping="{SERVO_CLASS["damping"]}" frictionloss="{SERVO_CLASS["frictionloss"]}" armature="{SERVO_CLASS["armature"]}" limited="true"/>')
    w(f'      <position kp="{SERVO_CLASS["kp"]}" forcerange="-{SERVO_CLASS["force"]} {SERVO_CLASS["force"]}"/>')
    w('    </default>')
    w('    <default class="visual"><geom contype="0" conaffinity="0" group="1" rgba="0.55 0.7 0.85 1"/></default>')
    w('    <default class="foot"><geom type="sphere" contype="1" conaffinity="1" condim="3" friction="0.8" rgba="0.3 0.3 0.3 1"/></default>')
    w('  </default>')
    if meshes:
        w('  <asset>')
        for name in bodies:
            w(f'    <mesh name="{name}" file="{name}.stl" scale="0.001 0.001 0.001"/>')
        w('  </asset>')
    w('  <worldbody>')
    w('    <light pos="0 0 2" dir="0 0 -1" directional="true"/>')
    w('    <geom name="floor" type="plane" size="0 0 0.05" contype="1" conaffinity="3" friction="0.8" rgba="0.9 0.9 0.9 1"/>')
    hip = bodies['torso']['origin']
    w(f'    <body name="torso" pos="{v3(hip)}">')
    w('      <freejoint name="floating_base"/>')
    w('      <site name="imu" pos="0.06 0 0.02"/>')
    w('      ' + inertial(bodies['torso']))
    bb = torso.solid().bounding_box()                             # torso_frame, body-native frame: X ventral depth, Y width, Z along the spine
    centre = np.array(tuple((A.body_location(pose) * Pos(*tuple(bb.center()))).position)) - hip
    w(f'      <geom name="torso_box" type="box" size="{v3([s / 2 for s in tuple(bb.size)])}" pos="{v3(centre)}" euler="0 {90-theta:.4f} 0" contype="2" conaffinity="2" group="3" rgba="0.6 0.6 0.7 0.3"/>')
    if not crude:
        w('      <geom class="visual" type="mesh" mesh="torso"/>')
    acts = []
    def emit(name, depth):
        b = bodies[name]; ind = '  ' * depth
        parent = bodies[b['parent']]
        w(f'{ind}<body name="{name}" pos="{v3(b["origin"] - parent["origin"])}">')
        j = b['joint']
        w(f'{ind}  <joint name="{j["name"]}" class="sts3215" axis="{ax(j["axis"])}" range="{j["range"][0]} {j["range"][1]}"/>')
        w(f'{ind}  ' + inertial(b))
        acts.append(j['name'])
        children = [n for n, c in bodies.items() if c['parent'] == name]
        if crude:
            end = bodies[children[0]]['origin'] if children else b['foot']
            r = {'carrier': 0.012, 'upper': 0.014, 'lower': 0.010}[name.rsplit('_', 1)[1]]
            w(f'{ind}  <geom class="visual" type="capsule" size="{r}" fromto="0 0 0 {v3(end - b["origin"])}"/>')
        else:
            w(f'{ind}  <geom class="visual" type="mesh" mesh="{name}"/>')
        if 'foot' in b:
            f = b['foot'] - b['origin']
            w(f'{ind}  <geom name="{name.rsplit("_", 1)[0]}_pad" class="foot" size="{P.BODY_FRONT_FOOT_RADIUS_MM*MM:.4f}" pos="{v3(f)}" mass="0"/>')
            w(f'{ind}  <site name="{name.rsplit("_", 1)[0]}_foot" pos="{v3(f)}"/>')
        for c in children:
            emit(c, depth + 1)
        w(f'{ind}</body>')
    for name, b in bodies.items():
        if b['parent'] == 'torso':
            emit(name, 3)
    w('    </body>')
    w('  </worldbody>')
    w('  <actuator>')
    for a in acts:
        w(f'    <position class="sts3215" name="{a}" joint="{a}" inheritrange="1"/>')
    w('  </actuator>')
    w('  <sensor>')
    w('    <gyro site="imu" name="gyro"/><accelerometer site="imu" name="accelerometer"/><framezaxis objtype="site" objname="imu" name="upvector"/>')
    for a in ('rear_right', 'rear_left', 'front_right', 'front_left'):
        w(f'    <framepos objtype="site" objname="{a}_foot" name="{a}_foot_pos"/>')
    w('  </sensor>')
    w('  <keyframe>')
    w(f'    <key name="home" qpos="{v3(hip)} 1 0 0 0 {" ".join("0"*12)}" ctrl="{" ".join("0"*12)}"/>')
    w('  </keyframe>')
    w('</mujoco>')
    out.write_text('\n'.join(L) + '\n')
    record = {
        'model': out.name, 'pose': pose_name, 'crude': crude, 'total_g': total, 'com_world_mm': com.tolist(),
        'prints_g': table, 'servo_g': SERVO_G, 'servo_box_mm': SERVO_CASE, 'density_g_cm3': DENSITY,
        'bodies': {n: {'mass_g': b['mass_g'], 'com_world_mm': b['com'].tolist(),
                       'items': {it['name']: {'mass_g': it['mass_g'], 'source': it['source']} for it in b['items']},
                       **({'mesh': {'kind': meshes[n][0], 'bytes': meshes[n][1]}} if meshes else {})} for n, b in bodies.items()},
        'joint_ranges_deg': RANGE, 'joint_ranges_source': 'docs/design/walking/viewer-endpoints.json initial_pose_bounds.walking (shared slider, not per joint)',
        'actuator': 'Open Duck 7.4 V BAM placeholder', 'omitted': 'fasteners, screw heads, neck envelopes, battery, electronics, head, cables'}
    out.with_suffix('.json').write_text(json.dumps(record, indent=1) + '\n')
    print(f'wrote {out} | total {total:.0f} g | CoM world mm {np.round(com, 1).tolist()}'
          + (f' | meshes {sum(m[1] for m in meshes.values())/1e6:.2f} MB' if meshes else ''))
    for e, r in sorted(table.items()):
        print(f'  {e:24s} {r["mass_g"]:6.1f} g  (solid {r["solid_g"]:6.1f} g)  {r["source"]}')
    for n, b in bodies.items():
        print(f'  body {n:20s} {b["mass_g"]:6.1f} g' + (f'  mesh {meshes[n][0]} {meshes[n][1]/1e3:.0f} kB' if meshes else ''))
    return bodies


if __name__ == '__main__':
    args = [a for a in sys.argv[1:] if not a.startswith('--')]
    crude = '--crude' in sys.argv
    build(args[0] if args else ROOT / 'sim' / ('koala_walking_crude.xml' if crude else 'koala_walking.xml'), crude=crude)

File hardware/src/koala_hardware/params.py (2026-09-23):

# SPDX-License-Identifier: CERN-OHL-S-2.0
"""Single source of dimensional truth (mm). DEC-09: bed_size and scale are parameters.

Provenance tags:
  [STEP]    measured from vendor STEP (vendor/so-arm100/STS3215_03a.step)
  [VENDOR]  stated on the vendor product page
  [STD]     published standard (Arduino Uno drawing, insert catalogues)
  [SPEC]    stated in the Feetech ST-3215-C018 product specification (A/0,
            2023-07-20) - the vendor's own document, which outranks the STEP
  [VERIFY]  best-available figure - confirm against the physical part before
            printing anything that depends on it (see parts/coupons.py)
  [MEASURED] confirmed by a printed coupon on the reference printer, dated;
            results and their caveats live in docs/test-log.md
  [DESIGN]  chosen design target or nominal geometry, not a measurement
  [SUPPLIED] read off hardware that arrived in the box, dated; what the vendor
            actually ships, which is not always what the spec sheet says
"""

# --- Printer / process -------------------------------------------------------
BED_X = 200.0  # DEC-09 hard limit
BED_Y = 200.0
BED_Z = 200.0

# Fit constants - calibrate once with the coupon prints on the Ender-5 S1,
# then they hold for every part (DEC-23). These are REFERENCE-PRINTER values:
# derive them from a coupon *fit* (smallest size that accepts the real part),
# on a printer whose flow and XY accuracy are already calibrated - otherwise
# they absorb that machine's error. See hardware/README "Reading a coupon
# result".
CLEAR_POCKET = 0.25   # [VERIFY] generic non-servo fits; servo uses SOCKET_CLEAR
CLEAR_HOLE_M3 = 3.4   # [MEASURED 2026-09-01] coupon_ladder: 3.4 slides free,
                      # 3.2 threads in by hand (too tight for a clearance hole)
CLEAR_HOLE_M2_5 = 2.9 # [VERIFY] not yet coupon-tested; scaled from M3
INSERT_M3_DIA = 4.0   # [VERIFY] M3 brass heat-set: nominal boss hole
INSERT_M3_LEN = 5.7
CAP_M3_DIA = 5.5      # [STD] M3 socket cap head across the flats' circle
CAP_M3_H = 3.0        # [STD] cap head height - what stands proud (DEC-25)
WALL = 3.0            # default structural wall
PLATE = 5.0           # default structural plate thickness

# --- Shared ST3215 / SO-101 horn inputs ------------------------------------
SERVO_AXIS_X = 12.5    # [SPEC] axis offset from case length centre
SERVO_DRIVE_SQ = 9.9   # [STEP] SO-101 printed horn hole pattern
SERVO_MASS = 55.0      # [SPEC] per bare servo, nominal
SELFTAP_DIA = 2.0      # [SUPPLIED 2026-09-07] M2x5 case-lug screws (Waveshare); RCmall packs read M2x6, unmeasured (test-log 2026-09-12)
HORN_SCREW = "M3x6"    # [SUPPLIED 2026-09-08] pan head, in the Waveshare ST3215 box;
HORN_SCREW_HEAD_DIA = 5.2  # [SUPPLIED 2026-09-08] Waveshare box; RCmall packs ship the same M3x6 pan head, head not re-measured (2026-09-12)
HORN_SCREW_HEAD_H = 2.0    # [SUPPLIED 2026-09-08] upstream's fork counterbores are too
                           # small for these heads; size koala's to them

# --- Drive motor - DFRobot FIT0403 37D 12V 122rpm w/encoder (Pi Hut) ---------
# Manufacturer drawing:
# https://dfimg.dfrobot.com/wiki/17480/FIT0403_gb37y3530-12v-90en_dimension_1.0.jpg
MOTOR_DIA = 37.0        # [VENDOR] gearbox diameter
MOTOR_BODY_LEN = 69.0   # [VENDOR] mounting face -> encoder cap: 6+24+29+10
MOTOR_LEN = 90.0        # [VENDOR] overall envelope: 69 body + 21 shaft
MOTOR_FACE_BOSS_DIA = 12.0  # [VERIFY] centre boss on faceplate
MOTOR_FACE_BOSS_H = 2.0     # [VERIFY]
MOTOR_BCD = 31.0        # [VENDOR] 6x M3, adjacent spacing 15.5 => hex on d31
MOTOR_FACE_SCREWS = 6
MOTOR_SHAFT_DIA = 6.0   # [VENDOR] D-shaft
MOTOR_SHAFT_LEN = 21.0  # [VENDOR] mounting face -> shaft tip
MOTOR_D_LEN = 15.5      # [VENDOR] length of the D-shaped portion

# --- Wheel & hub (Pololu 80x10 + 6mm universal hub) --------------------------
WHEEL_DIA = 80.0        # [VENDOR] DEC-19 fixed control constant
WHEEL_W = 10.0          # [VENDOR]
HUB_DIA = 25.4          # [VENDOR] Pololu 1999 mechanical drawing
HUB_T = 9.5             # [VENDOR] axial thickness
HUB_STACK = 18.0        # [VERIFY] clears 5 mm cheek + 3 mm heads + 9.5 mm hub
WHEEL_CLEAR = 4.0       # radial/axial clearance kept around the tyre

# --- Electronics (tray patterns) --------------------------------------------
# Arduino Uno R3 hole pattern (TB9051FTG shield) - origin at board corner.
UNO_BOARD = (68.58, 53.34)                       # [STD]
UNO_HOLES = [(13.97, 2.54), (15.24, 50.8),
             (66.04, 17.78), (66.04, 45.72)]     # [STD]
TEENSY_BOARD = (35.56, 17.78)                    # [STD] no mounting holes
BNO085_BOARD = (25.4, 19.5)                      # [VERIFY] Adafruit 4754
STANDOFF_H = 5.0        # printed standoffs under the driver shield
TRAY_GAP = 10.0         # bought M3 standoffs, pelvis top -> tray underside
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

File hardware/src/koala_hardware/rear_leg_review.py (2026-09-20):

# SPDX-License-Identifier: CERN-OHL-S-2.0
"""Production rear-leg clearance and viewer with the DEC-61 45-degree mount.

Run from hardware: .venv/bin/python -m koala_hardware.rear_leg_review
The actual production torso is included. Front limbs, their mounting hardware,
the neck allocation, cables and loaded locomotion are outside this review.
The two optional thigh studies retain their historical geometry and status.
"""
from functools import lru_cache
from pathlib import Path
from itertools import combinations
from math import radians, cos, sin
from unittest.mock import patch
import argparse
import hashlib
import json
import shutil
import subprocess
import tempfile
from build123d import Pos, Rot, Plane, mirror, Compound, export_step
from . import assembly as A, body_plan as B, params as P, servo_iface as S, audit
from .parts import links as L, pelvis, torso, neck_space

ROOT=Path(__file__).resolve().parents[3]
OUT=ROOT/'docs/design/rear-leg'
LIVE=ROOT/'hardware/build/viewer/rear-leg'
OUT_OPT=ROOT/'docs/design/rear-leg/thigh-options'
OUT_FLAT=ROOT/'docs/design/rear-leg/thigh-flat'
THIGH_OPTIONS=False   # --thigh-options: left leg = option 1 frame thigh, right leg = option 2 split thigh
THIGH_FLAT=False      # --thigh-flat: both legs = option 3, the owner's one-piece tapered thigh (2026-09-19)


def out_dir():return OUT_FLAT if THIGH_FLAT else OUT_OPT if THIGH_OPTIONS else OUT


def flat_thighs(pose):
    limb=B.poses()[pose]['rear'];upper=A.segment_frame(limb.root,limb.bend,L.rear_axis_y())
    flat=L.rear_thigh_flat(P.BODY_THIGH_MM)
    return [('rear_thigh_right',upper*flat,'#c98fd9','rear_roll',1),('rear_thigh_left',mirror(upper*flat,Plane.XZ),'#c98fd9','rear_roll',-1)]


MOTOR_ITEMS=('rear_motor','rear_shaft','rear_hub','rear_wheel','reference_rear_motor_heads')


def flush_shanks(pose,items):
    """Both shanks with the motor inset (owner's shank option); the bought motor stack moves inboard with it."""
    limb=B.poses()[pose]['rear'];lower=A.segment_frame(limb.bend,limb.axle,L.rear_axis_y())
    shank=L.lower_link(P.BODY_SHANK_MM,False,P.SHANK_MOTOR_INSET);shift=lower*Pos(-P.SHANK_MOTOR_INSET,0,0)*lower.inverse()
    out=[]
    for n,s,c,g,side in items:
        base=n.removesuffix('_right').removesuffix('_left')
        if base=='rear_shank':s=lower*shank if side>0 else mirror(lower*shank,Plane.XZ)
        elif base in MOTOR_ITEMS:s=shift*s if side>0 else mirror(shift*mirror(s,Plane.XZ),Plane.XZ)
        out.append((n,s,c,g,side))
    return out


def option_thighs(pose):
    """Replacement rear-thigh items for the two print-form options (2026-09-19 review)."""
    limb=B.poses()[pose]['rear'];upper=A.segment_frame(limb.root,limb.bend,L.rear_axis_y())
    body,cheek=L.rear_thigh_split(P.BODY_THIGH_MM);frame=L.rear_thigh_frame(P.BODY_THIGH_MM)
    return [('rear_thigh_right',upper*body,'#c98fd9','rear_roll',1),
            ('rear_thigh_cheek_right',upper*cheek,'#f0b8ff','rear_roll',1),
            ('reference_rear_thigh_lap_fixings_right',upper*L.thigh_lap_fixings(),'#aaaaaa','rear_roll',1),
            ('rear_thigh_left',mirror(upper*frame,Plane.XZ),'#c98fd9','rear_roll',-1)]


def frames(pose):
    # DEC-61: the assembly's own frames already carry the 45 degree rear mount.
    return [(n,m,tf) for n,m,tf in A.socket_frames(pose) if '_rear_' in n]


@lru_cache
def nominal(pose):
    out=[]
    for n,s,c,g,side in A.nominal_details(pose):
        if not (n.startswith(('rear_','reference_rear_','pelvis_socket_','reference_pelvis_','torso_frame'))):continue
        out.append((n,s,c,g,side))
    if THIGH_OPTIONS:out=[o for o in out if not o[0].startswith('rear_thigh_')]+option_thighs(pose)
    elif THIGH_FLAT:out=flush_shanks(pose,[o for o in out if not o[0].startswith('rear_thigh_')]+flat_thighs(pose))
    return out


def details(pose='quadruped',roll=0,pitch=0,knee=0):
    out=[];d=A.joint_data(pose)['rear']
    for n,s,c,g,side in nominal(pose):
        if side:
            if side<0:s=mirror(s,Plane.XZ)
            s=A.joint_transform(d,g.split('_')[-1],roll,pitch,knee)*s
            if side<0:s=mirror(s,Plane.XZ)
        out.append((n,s,c,g,side))
    return out


def collisions(pose='quadruped',roll=0,pitch=0,knee=0,cache=None):
    """All rear solids, including rigid hardware pairs and both legs."""
    data=details(pose,roll,pitch,knee);fits={};d=A.joint_data(pose)['rear']
    for n,m,tf in frames(pose):
        joint='fixed' if '_pitch_' in n else 'pitch' if '_roll_' in n else 'roll'
        zone=A.joint_transform(d,joint,roll,pitch,knee)*tf*audit.contact_zone()
        for side in ('right','left'):
            fits[frozenset((n.replace('right',side),m.replace('right',side)))]=zone if side=='right' else mirror(zone,Plane.XZ)
    out=[]
    for (n,a,_,ga,sa),(m,b,_,gb,sb) in combinations(data,2):
        if audit.wheel_hardware(n) and audit.wheel_hardware(m) and sa==sb:continue
        key=(pose,n,m,roll,pitch,knee)
        if cache is not None:
            levels={'fixed':0,'pitch':1,'roll':2,'bend':3}
            if sa==sb or sa==0 or sb==0:
                lo,hi=sorted((levels[ga.split('_')[-1]],levels[gb.split('_')[-1]]))
                key=(pose,n,m,(pitch,roll,knee)[lo:hi])
            if key in cache:
                if cache[key]:out.append(cache[key])
                continue
        hit=None;v=audit.overlap(a,b)
        if v>.01:
            zone=fits.get(frozenset((n,m)))
            if zone is None or v>50 or audit.overlap(a-zone,b)>.01:
                hit={'parts':[n,m],'intersection_mm3':round(v,6)};out.append(hit)
        if cache is not None:cache[key]=hit
    return out
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

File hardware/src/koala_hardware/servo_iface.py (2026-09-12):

# SPDX-License-Identifier: CERN-OHL-S-2.0
"""Koala four-ear saddle and integrated-fork interfaces, DEC-33/40.

Servo face words (docs/soarm-joint-pattern.md, Terminology): FRONT = drive-horn
face = +X; BACK = idler/connector face = -X; BOTTOM = the end the servo stands
on = Z 0; TOP = the end nearest the output axis = Z 45.23; SIDES = +-Y. The
saddle has a floor under the Bottom, a Front wall and a Back wall (the pair
34.9 apart away from the ear bosses), with enclosing Side returns and a rounded outer footprint. The clevis has a Front plate (drive horn) and a Back plate (idler).
Body mounts use the CASE datum; horns use the OUTPUT AXIS datum. These are
independent feature families (test-log 2026-09-02). Nominal printed-part
interfaces are adopted from SO-101; no pocket derives from a servo model.
"""
from functools import lru_cache
from build123d import Box, Cylinder, Part, Pos, Rot, Align, Axis, fillet, RectangleRounded, extrude, Polygon
from . import params as P

# Restart primitive frame: X = output axis, Y = case width, Z = case length.
# BODY features use rear face Z=0; HORN features use Z=SOCKET_AXIS_Z.
# These are independent datums (test-log 2026-09-02); never locate a lug from
# a horn hole.


def _box(x0, x1, y0, y1, z0, z1):
    return Pos(x0, y0, z0) * Box(x1-x0, y1-y0, z1-z0,
        align=(Align.MIN, Align.MIN, Align.MIN))


def _x_hole(x0, x1, y, z, diameter):
    return Pos(x0, y, z) * Rot(Y=90) * Cylinder(diameter/2, x1-x0,
        align=(Align.CENTER, Align.CENTER, Align.MIN))


def _socket_bounds():
    return (P.SOCKET_CASE_X/2 + P.SOCKET_CLEAR,
            P.SOCKET_CASE_Y/2 + P.SOCKET_CLEAR)


def ear_face(side):
    return P.SOCKET_SEAT_OFFSET + (1 if side == 'drive' else -1)*P.SOCKET_EAR_X/2
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

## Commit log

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2026-09-01 DEC-15 size 40-50cm (child audience) + DEC-16 driver confirmed + child-safety
    - DEC-15: ~40-50cm, "big toy smaller than the child" (grandkids 2-5); resolves OQ-01.
    Lighter robot -> generous actuator headroom; makes child-safety a hard requirement.
    - DEC-16: Pololu Dual TB9051FTG confirmed at this mass class; resolves OQ-07.
    - concept.md principle 7 (child-safe by design) + OQ-10 (safety spec to resolve in design).
    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
2026-09-01 DEC-17 rear leg: motor-in-thigh, wheel-at-knee, leg ends at knee (resolves OQ-02)
    - Drive motor in the thigh; wheel at the outer knee in constant ground contact.
    - V1 leg ends at the knee; knee is a designed-in expansion interface for a future
    lower leg + foot + servo - deferred and gated on need (walking now conditional).
    - Terminology: "wheel-feet" -> "knee-wheels" across docs; roadmap/backlog updated.
    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
2026-09-01 DEC-18 Teensy 4.0 (resolves OQ-05) + DEC-19 drive-base BOM & wheel Ø80mm
    Order placed for the self-balancing base: TB9051FTG driver, 2x 37D motors,
    Pololu 80x10mm wheels + 6mm hubs, BNO085 IMU, Teensy 4.0 (~£159.50). Wheel
    diameter 80mm banked as a fixed control constant. Confirmed BOM in sourcing.md.
    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
2026-09-01 DEC-20: power integrity as first-class (banked from InMoov)
    Bench-PSU transient noise on a shared rail (brownouts, servo jitter, MCU/IMU
    resets, I2C corruption) was a real InMoov failure mode. Prototype from a stiff
    LiPo, isolate the logic rail, bulk caps on the servo bus, 3S only (not 4S),
    fuse the pack. Enriched architecture.md Power section.
    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
2026-09-01 DEC-21: keep servo mounting SO-ARM100 compatible (resolves OQ-08)
    Limb joints adopt the SO-ARM100 servo+bracket standard so off-the-shelf kits
    drop in and we inherit the LeRobot ecosystem; body/personality stay custom.
    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
2026-09-01 DEC-22 servos ordered (resolves OQ-06); both V1 hardware orders placed
    All V1 actuation + compute purchased 2026-09-01:
    - Pi Hut drive/balance base (~£159.50): Teensy, TB9051FTG, 2x 37D, wheels+hubs, BNO085.
    - RCmall servos (~£302): 12x STS3215 12V (limbs, +FE-URT-1), 4x STS3032M (neck, 6V bus),
    1x bracket set as dimensional reference (brackets are printed, DEC-21 clarified).
    Neck actuator = STS3032M (same STS protocol as limbs, own 6V bus). sourcing.md BOMs
    marked PURCHASED; architecture.md head row updated.
    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
2026-09-01 Doc coherence pass: fix wheel-footed stragglers, stale OQ-05 ref, gitignore pattern
    - "wheel-footed"/"wheel-foot" -> knee-wheeled terminology (DEC-17: leg ends at
    the knee, there are no feet) in README, AGENTS, concept, roadmap
    - firmware/README: Teensy 4.0 is decided (DEC-18), no longer a candidate
    - sourcing: fold pre-purchase research into one reference section (orders placed)
    - .gitignore: *.stl.gcode matched nothing; split into *.stl and *.gcode
    Claude-Session: https://claude.ai/code/session_01PGdy7URTJNHkoxC4GD6t5P
2026-09-01 DEC-23: part decomposition - one master model, screw-joined designed seams
    M3 + heat-set inserts, registration features, load-aware seam placement,
    automated 200x200 fit + interference check in the CAD pipeline.
    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
2026-09-01 DEC-24: enforce support-free printing; rework lower body to pass it
    Bed fit was checked but printability was not - the pelvis's declared
    orientation stood it on four 8 mm bosses (bed 204 mm2, overhang 17451 mm2).
    - printability.py: per-part bed-contact + overhang area (45 deg self-support
    limit), ranks the six principal orientations; export now FAILS on
    bed < 300 mm2 or overhang > 800 mm2
    - pelvis -> flat pelvis_plate (features one face only) + separate
    hip_bracket parts; tray now on bought M3 standoffs, no proud bosses
    - hip_bracket: cavity opens through (a floor becomes a bridged ceiling when
    flipped); servo held by its rear-tab screws
    - hip_link: small discs on vertical legs, pri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
    [export.py, params.py, pelvis.py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]
2026-09-01 hardware: prune stale build output for renamed parts
    Renaming pelvis -> pelvis_plate and thigh_right -> thigh_upper_right left the
    old v0 STLs beside the new ones. A stale file slices just as happily as a
    current one, so the exporter now deletes outputs whose part no longer exists.
    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
    [export.py]
2026-09-01 docs/bom.md: BOM with a CAD-generated printed-parts table; export both hands
    - bom.md: bought parts (ordered + the fasteners still to order) plus a
    printed-parts table written by the export, so it cannot drift from geometry
    - handed parts now export _right AND _left STLs; relying on the operator to
    mirror in the slicer is a wrong-handed print waiting to happen
    - hip_bracket is symmetric in Y: one part, qty 2, not a handed pair
    Lower body: 10 structural parts, 559 cm3 solid (~710 g PETG at 100%).
    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
    [export.py, pelvis.py]
2026-09-01 bom: measured filament and print time from the real slicing pipeline
    "PETG solid" read as a recommendation; it was only an upper bound. Replaced
    with figures measured by slicing every STL through the standing PETG profile
    on the print host (PrusaSlicer CLI on the printer's Pi, over Tailscale).
    - slice_remote.py: slices all exported STLs on the print host and caches the
    results; optional, so the CAD build never depends on the printer being up
    - bom.md: real per-part filament + time; structural lower body is 355 g and
    ~34.5 h, against the 710 g it would take printed solid
    - print profile section now documents the ACTUAL profile (3 perimeters, 15%
    grid) instead of a profile I invented; f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
    [export.py]
2026-09-01 hardware: how to read a coupon result (design clearance vs printer error)
    The reference printer is newly commissioned, so the first coupons double as
    printer calibration. A coupon measures design clearance and machine error
    together; folding a result into params.py before flow and XY accuracy are
    settled would bake one machine's error into the published design.
    Records the protocol: judge coupons by fit not calipers, calibrate the printer
    first, and treat params.py constants as reference-printer values that other
    builders re-derive by running the same coupons.
    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
    [params.py]
2026-09-01 Act on print-session feedback: slicing guard + de-circularise the profile
    1. slice_remote refuses to run while the printer is printing. Slicing loads
    the same Pi that runs Klipper, so a dozen back-to-back slices mid-job risk
    stutter, blobs or a "Timer too close" abort - the one way this tooling can
    damage a print, and it was undocumented. Asks Moonraker for print_stats
    first; --force is for a non-Klipper slicing host, not impatience.
    (Verified live: refused against the running coupon_ladder job.)
    2. The BOM presented the print host's general-purpose toy profile as
    koala-bot's standard, purely because it was what measured the parts. Split
    into what the DESIGN requires (P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
2026-09-01 bom: exact fastener counts from the CAD; fix too-short tab screw
    Counts were hand-waved ("~30"); they are now derived from the part modules'
    own bolt patterns, with the source of each quantity named.
    Two real errors found in the process:
    - the hip-bracket tab screws were listed as M3x50, but the span across the
    end walls is 47.2 mm - no room for a nyloc. Now M3x55.
    - M3 nuts for those screws were missing from the BOM entirely.
    Also records that INSERT_M3_DIA/LEN are written to the 5.7 x 4.6 mm insert
    geometry, so a different insert profile means re-deriving the constants.
    Claude-Session: https://claude.ai/code/session_01PGdy7URTJNHk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
2026-09-01 DEC-25: socket cap heads proud by default; no countersinks in printed plastic
    Every joint was a plain clearance hole with a proud head - a default I fell
    into rather than chose. Now a decision with reasons: countersunk cones wedge
    printed layers apart under load, cap heads take more torque during repeated
    bring-up disassembly, and 3 mm of proud head costs nothing on an internal
    joint. Counterbore (flat pocket, never a cone) only where a head would foul,
    with that face printed upward so the pocket is open air not a bridge.
    Exception: heads on exposed outer surfaces get recessed or panelled over, per
    the child-safety principle (OQ-10).
    Adds fasteners.m3_counterbore and the M3 cap head dimens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
    [params.py]
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2026-09-01 test-log: first coupon results - CLEAR_HOLE_M3 confirmed, machine accurate
    coupon_ladder printed 2026-09-01, the first koala-bot part on a plate.
    - M3 clearance: 3.4 slides free, 3.2 threads in by hand. CLEAR_HOLE_M3 = 3.4
    CONFIRMED unchanged - the assumption held, nothing needs reprinting
    - 150 x 60 x 6 came out accurate, which clears the calibration confound: this
    machine's coupon results can now be trusted as design constants
    - no corner lift on a 150 mm flat slab, which is what pelvis_plate and e_tray
    were waiting on
    Adds docs/test-log.md as the home for "what the part actually showed",
    including no-change results, and a [MEASURED] provenance tag in params.py.
    Insert bores remain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
    [params.py]
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2026-09-02 servo: separate body mount from horn drive, and record what is unverified
    Consolidates a long investigation into one commit. Replaces five local
    commits that recorded its dead ends as if they were findings.
    THE CATEGORY ERROR. The STS3215 has two independent feature families on
    two different datums: the BODY mount (case datum, corners at y=+/-10.4,
    does not rotate) and the HORN drive (output-axis datum, 9.9 mm square
    on a Ø20 disc, rotates). servo_iface.on_axis() puts both in one frame,
    which makes them look comparable. Every wrong turn in this session was
    a swap between the two. params.py is now organised around the split,
    with the datum stated for each family.
    REAL FIX. Drive-square scr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
    [params.py, servo_iface.py]
2026-09-02 forks: bolt the idler horn instead of boring past it
    The idler face carries a SECOND metal horn with the same 4-hole square,
    free-spinning about the output axis, there to give the joint axial
    alignment. Three sources already said so and none were read that way:
    the STEP shows the 9.9 mm square at both Z ends, upstream's bracket
    carries the pattern on two walls 36.4 mm apart, and
    drive_hole_cutters()'s own docstring says "bolts onto the horn (or
    idler)".
    hip_link and thigh_upper both cut a plain Ø20.5 clearance bore through
    the aft plate - removing exactly the material that should bolt to the
    idler horn, and leaving every driven joint a cantilever hanging off one
    horn where upstream builds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
    [params.py]
2026-09-03 DEC-26: compact hip - pitch servo aft and outboard, axes 26 mm not 60
    The roll and pitch axes sat 60 mm apart, which read as a hip plus a
    knee halfway down the thigh. That gap was never a choice:
    BRACKET_CLEAR_R (24) + SERVO_ABOVE (35.2) = 59.2. The pitch servo was
    standing on the roll servo's head, pointing up.
    The fix uses a degree of freedom the old layout never touched: a
    servo's output axis runs through its body, so sliding it ALONG that
    axis does not move the axis at all. Pointing the pitch servo aft and
    sliding it outboard makes the binding clearance the roll servo's
    half-body below its axis (10.2) against the pitch servo's half-WIDTH
    (12.4) rather than its half-length. HIP_PITCH_DRO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
    [params.py]
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2026-09-06 viewer: local 3D viewer in the repo, refreshable from any harness
    `uv run python -m koala_hardware.viewer` rebuilds build/viewer/scene.json from
    the live CAD, copies the checked-in viewer.html beside it, and serves both on
    localhost:8017. --build regenerates data only, --serve skips the rebuild,
    --port moves it. Regenerate and reload the tab; nothing is published anywhere.
    Two tabs: the posed assembly, split into printed parts, bought parts and servo
    keep-out ghosts; and every printed part in its declared print orientation laid
    out against a 200 mm bed square for scale. Click a row to isolate a part,
    shift-click to hide it.
    build_scene() now yields (name, solid, colour) so the sidebar can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
    [viewer.py]
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2026-09-07 DEC-29: lower body rebuilt around the bed, not around the servo
    Replaces the geometry the review condemned. The pelvis and its roll roots
    become one part printed deck-down, dropping two mounting flanges and eight
    screws. The enclosing hip link becomes flat roll cheeks, an open pitch saddle
    and a removable case cap, so the pitch servo is clamped rather than trapped
    behind invented case screws. The thigh becomes two flat cheeks on through-
    bolted compression spacers, with the outer cheek acting as the motor
    faceplate - no insert-loaded seam, and no fastener with nowhere to go.
    Track widens to 258.8 mm and the pitch axis moves 20 mm forward to open the
    inner-thigh lane. That is prototype evide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
    [export.py, params.py, pelvis.py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]
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2026-09-07 BOM: the servo case screw is M2, and M2x5 will not reach
    Two Waveshare ST3215 12V servos bought from Amazon as test-fit hardware settle a
    constant that was an explicit guess. Their box holds M2x5 self-tapping screws for
    the case fixing holes, so SELFTAP_DIA drops 2.5 -> 2.0, clearance 2.8 -> 2.4 on
    the M3 coupon's +0.4 convention, and pilot 2.1 -> 1.7. params.py gains a
    [SUPPLIED] provenance tag, because what arrives in a box is a different class of
    evidence from a spec sheet or a STEP file.
    That box also contradicts a claim this repo asserted in three places: [SPEC 11]
    "No Accessories" describes the bare Feetech part, not a retail box, which does
    ship horn screws. Annotated where asserted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
    [params.py]
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2026-09-08 Replace discarded lower body with SO-101 joints and articulating knees
    Implement DEC-32/33/34: shared cradle/collar/clevis interfaces, new pelvis and leg builders, ankle wheel-feet, and a complete joint fit rig. Add knee kinematics to the viewer and audit, derive fastening quantities through export, and record requirements, packaging tradeoffs and Tailscale viewer access.
    Validated 23 STL exports, 27 local and 81 opposing-leg poses, full-depth fastening probes, eight unit tests, and browser/CAD pose parity. Physical fit, sliced layers, continuous clearance, cable routing and load/creep behaviour remain unverified; the printer was busy and no new print was started.
    [export.py, leg_sizing.py]
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2026-09-08 Horn span is 36.4, not 37.5: first caliper reading corrects the DEC-34 clevis
    Calipers on a Waveshare ST3215 with both horns fitted read 36.4 mm outer face
    to outer face, and the printed SO-101 Rotation_Pitch fork is 36.4 inner face
    to inner face. Upstream's assembly CAD, which DEC-33 adopted, said 37.5; the
    SO-100 bracket measurement of 2026-09-02 (36.4) had been right. Every
    span-derived figure moves 1.1 mm through params.py: drive-face datum, crossbar
    35.6, motor face, track 237.3, bolt grips. Export, audit and the unit tests
    pass on the corrected geometry; the BOM table is regenerated. Remaining caliper
    items are listed in the test-log entry.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
    [params.py]
2026-09-08 The 37.5 span was my probing error, not upstream's: Rotation_Pitch STEP reads 36.4
    Rotation_Pitch_SO101.step has its clevis arm faces at Y = 10.0 and 46.4, so the
    part agrees with the caliper on the print and on the servo. The review's axis
    probe through the idler-side arm had read the floor of a ~1 mm centre recess
    instead of the arm face. Corrects the attribution in the pattern doc, params,
    test-log and DEC-33, and notes the idler-side plate needs that centre recess.
    Claude-Session: https://claude.ai/code/session_01E5SX8L1sqEqthFFMzcooLE
    [params.py]
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2026-09-08 Widest faces are asymmetric: seat mid-plane sits 0.5 toward the drive side; audit now fails
    Calipers: seat to widest is 2.5 on the drive side and 3.5 on the back
    (connector) side. With the pocket as datum the idler outer face is at -17.0,
    0.4 inside the widest back-face plane, and the drive face at 19.4; track
    238.2. The audit's rig sweep fails because socket_reference() is still a
    full-width box along the whole case; that is the true state and is left
    failing until the case model carries the measured axial extents of the three
    planes. Export and unit tests pass.
    Claude-Session: https://claude.ai/code/session_01E5SX8L1sqEqthFFMzcooLE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
    [params.py]
2026-09-08 Servo face terminology: Front, Back, Bottom, Top, Sides; docs rewritten to use it
    The maintainer asked for one vocabulary: rear/back/horn/idler face had become
    ambiguous. Defined once in soarm-joint-pattern.md (Terminology), mirrored in the
    params and servo_iface headers, and applied through the pattern doc, the brief's
    primitive table and the 2026-09-08 test-log section, which is consolidated into
    one table of the eight caliper readings plus the bench observations and the
    audit-failure explanation.
    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
    [params.py, servo_iface.py]
2026-09-08 Supplied horn screws: M3x6 pan head, head 5.2 x 2.0 (Waveshare box)
    Calipers. Upstream's fork counterbores do not fit these heads, so the koala
    plate needs >=Ø6 x >=2.5 pockets over the 3.5 web and the horn pad grows to
    ~6 thick. M3x6 through 3.5 leaves 2.5 for a 2.1 tapped idler body; rig check
    for bottoming. RCmall Feetech packs unverified.
    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
    [params.py]
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2026-09-08 Case reference now carries the measured profile; audit failure moves to the plate centres
    Back face regions from the lettered photos: ears 0-5.3 (31.8), widest 5.3-18.8
    (34.8, the pocket), then faces below the seat plane to the Top, with the Ø20
    idler seat a raised pad the idler covers exactly (IMG_6995); axis at 35.2.
    socket_reference() models ears, widest region, seat-level faces, idler, boss,
    drive horn and its pan head. The 229 mm3 idler-face failure clears; the audit
    now fails on the drive horn's pan head into the flat Front plate (26.4 mm3)
    and the servo boss into the flat Back plate (35.2 mm3 = pi*4^2*0.7), both
    already on the corrections list. Connector bay band 18.8-24.5 recorded;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
    [params.py, servo_iface.py]
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2026-09-08 Use the maintainer's STS3215 STEP as the case reference; keep the measured horn stack
    hardware/vendor/st3215/STS3215_c.step (FreeCAD model, author and licence still
    to record) has the right shape: centred pads, ear plane, connector bay, seat
    pads and Top step, all within 0.3 mm of the calipers except its horn stack,
    which is 0.85 too wide and is therefore not used. servo_iface.case_model()
    loads the three case solids into the socket frame; socket_reference() adds
    the idler, boss, drive horn and pan head from measured constants, and falls
    back to the parametric stepped profile if the file is absent. Import costs
    about 1.4 s per build. Deviation table in the vendor README.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
    [servo_iface.py]
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2026-09-12 Servos arrived and unboxed; four STS3215 to SO-ARM101; plus the 2026-09-08..11 layout and CAD work
    Servo facts (2026-09-12): RCmall order arrived — 12 STS3215, 4 STS3032M, bracket set.
    Each STS3215 ships two metal horns, M3×6 horn screws, M2×6 case screws, no bus adapter
    (the listed FE-URT-1 was not in either pack). STS3032M: fixed single lead, 3-port
    connector boards and a link cable, one aluminium + three plastic horns. Four STS3215
    reallocated to SO-ARM101 (wk-soarm101 DEC-09): eight of twelve in hand, re-order needed
    (bom.md, OQ-16). Neck bus chains board-to-board (architecture.md).
    Also commits the uncommitted design work from 2026-09-08 to 2026-09-11: DEC-36 to DEC-51
    (four wheel-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
    [body-quadruped.step, body-upright.step, flat-back-candidate.step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]
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2026-09-14 DEC-53 root socket: one handed module at all four roots, captive M3 nuts under the servo
    Replaces pelvis_socket and shoulder_socket. Plate 46.9 x 36.7 x 6 faces the torso; four M3 nuts sit
    captive in the socket shelf under the servo Bottom, M3x16 screws from the torso side. Pelvis
    modules are shoulder modules turned 180 deg about the pitch axis. Torso flange holes follow the
    nut pattern, rails moved to x=10..20, locating pins removed; torso shape itself deferred. Assembly,
    audit and access test updated; 24 tests pass; export clean; BOM regenerated. The DEC-49 carrier no
    longer clears the vertical rear case (viewer limit search fails on the upright pose) until it is
    re-derived under DEC-52. O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
    [params.py, pelvis.py]
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2026-09-14 DEC-55 hip carrier: body below the pitch axis, roll servo Bottom-down, thigh forks pass the roll socket; viewer builds again
    Rear carrier rebuilt (option 2): clevis bridge under the pitch servo's nose, 24 x 22 block to the roll
    socket, roll servo standing Bottom-down beside the pitch servo's drive pad; roll centres 128.1 mm.
    Thigh forks: horn/idler pads, tails stopped above the socket walls, cheeks outboard of the walls,
    slab under the socket floor doubling as the knee shelf. Shoulder keeps the DEC-49 carrier until
    DEC-54. Assembly/tests wired for front/rear carriers and flipped roll socket; 25 tests pass; export
    clean; viewer scene and limit search rebuild in both poses. Known costs from th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
    [params.py, viewer.py]
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2026-09-18 Refine rear carrier and links; preserve proposed 45-degree mount
    Add carrier and socket-orientation studies, revise the thigh yoke and knee case orientation, and extend the shank fork with filleted motor supports. Preserve the proposed 45-degree rear mounting in a separate review while retaining the main torso interface.
    Include CAD exports, images, clearance evidence, printability updates and generated BOM. Improve component-solid collision checks and use a two-degree viewer clearance reserve.
    Validation: 29 unittest checks pass; current clearance and manufacturing source hashes match. Physical fit, printing, strength and walking remain unverified.
    [angled-fork.step, pitch-socket-45.step, rear-leg-quadruped.step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]
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2026-09-20 Redesign recessed roll-first shoulders and harden CAD validation
    Extend the torso around removable shoulder cassettes with a 10 mm socket-lip recess. Apply rear-link printability lessons to the front chain and reserve a cartridge for the three small STS3032M neck servos.
    Fix rear driver access, cumulative fillets, internal-geometry fingerprints and version rollback protection. Correct STL roundoff persistence and implement front/rear joint-order-aware assembly and viewer transforms.
    Refresh part versions, BOM, drawings, STEP exports, slices and both viewers. Record 65 passing tests, the 62-pose audit, independent viewer endpoint checks and 11 current review slices. Changed parts remain unp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
    [body-quadruped.step, body-upright.step, rear-leg-quadruped.step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]
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2026-09-23 Add interchangeable footed rear shanks for walking-first build
    Add foot_shank v1 with the existing knee interface and shared TPU pad; retain wheeled shank v2. Include the walking assembly and viewer configuration, generated BOM quantities, print exports and validation records, and DEC-62 documentation.
    Validation recorded: 71 Python tests, 10 final targeted checks, JavaScript and browser regressions, CAD clearance audits and both handed review slices. New shanks remain unprinted.
    [body-walking.step, foot_shank_left-v1.step, foot_shank_right-v1.step]
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
